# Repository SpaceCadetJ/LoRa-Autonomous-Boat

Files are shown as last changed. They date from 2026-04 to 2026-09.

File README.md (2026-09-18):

# LoRa Autonomous Boat Controller

An embedded-systems project spanning **STM32 firmware, LoRa communication, PCB reconstruction and a documented V2 redesign**. The original university boat controller is preserved as V1; the next vehicle node and a voice/text/location handheld are under development.

**Current milestone: engineering review edition.** The schematics, source code, parts and build procedures are available for inspection. V2 is not fabrication-ready, and the preserved V1 firmware build is not hardware-qualified.

[Portfolio case study](docs/portfolio/README.md) · [Application handbook](docs/applications/README.md) · [Build and assembly guide](docs/build/README.md) · [Latest verification](reviews/codex/design_completion/HANDOFF.md) · [Project history](REPORT.md)

| Existing controller | Developing controller |
| --- | --- |
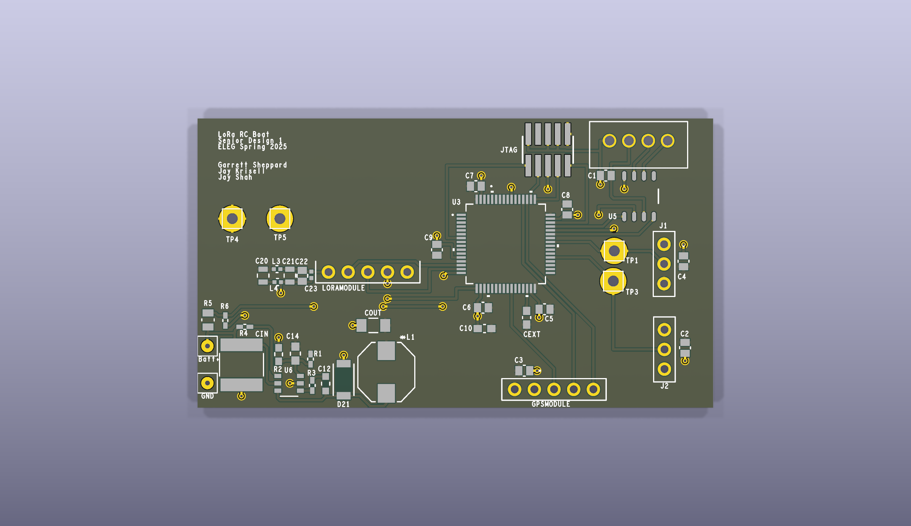
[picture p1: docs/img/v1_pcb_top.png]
V1 controller reconstructed in KiCad
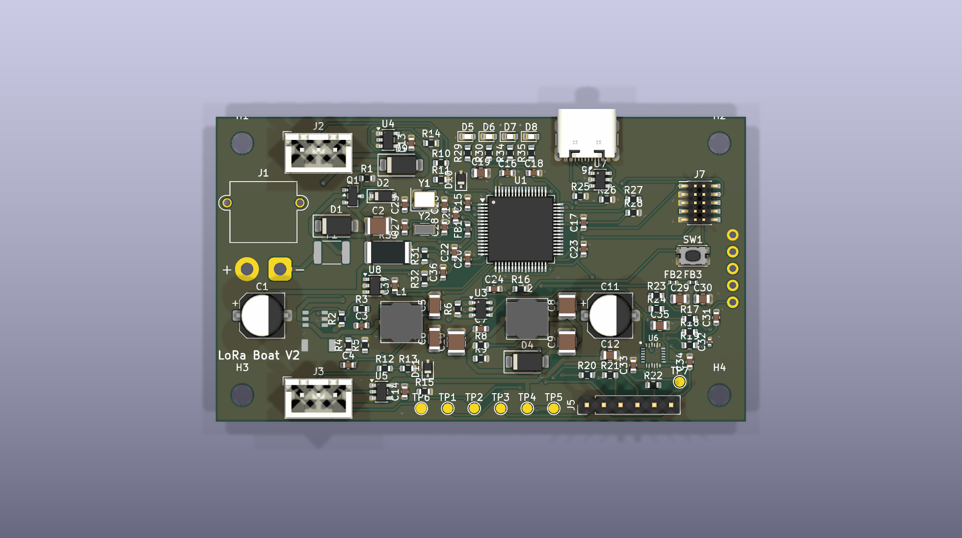
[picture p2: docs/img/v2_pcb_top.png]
V2 vehicle-node CAD draft
|  |  |
| V1: 44 physical components, reconstructed from original fabrication evidence | V2: 118 physical references, 80 × 46 mm board draft |

These are CAD renders. They do not establish that the V2 board has been manufactured or tested.

## Explore the project

Clone or download the repository, then open [pm/index.html](pm/index.html) locally. For the complete interactive workspace with searchable BOMs, datasheets, drawings, connector evidence and assembly/programming guides:

```sh
node pm/tools/serve.mjs
```

Open **http://127.0.0.1:8765/pm/**. The viewer runs locally and requires no account or package installation. GitHub displays the HTML source; it does not run the viewer from a repository file link. See [viewer instructions](pm/README.md).

The [portfolio handoff](docs/portfolio/README.md) and [structured project data](docs/portfolio/portfolio.json) provide captions, asset paths, result evidence and claim boundaries for a portfolio site.

## Architecture and implementation

```mermaid
flowchart LR
  Handset[External handset] <-->|LoRa radio link| Radio[Reyax UART radio]
  Radio <-->|UART| MCU[STM32F446 vehicle controller]
  GPS[GNSS receiver] -->|NMEA UART| MCU
  MCU -->|PWM| ESC[Propulsion ESC]
  MCU -->|PWM| Servo[Steering servo]
  Battery[Battery and regulation] --> MCU
```

V1 firmware is bare-metal C using STM32 HAL/CMSIS, with UART radio commands, GPS parsing and two PWM outputs. The original handset source is not included. The current code has known failsafe, parsing and pin-role issues documented in the [firmware audit](docs/research/FIRMWARE_REVIEW_NOTES.md).

Hardware originated in Cadence OrCAD/Allegro and has been reconstructed in KiCad 9. Python tools generate and inspect schematics, compare complete pin groups and prepare assembly evidence. The viewer uses HTML, CSS and JavaScript with embedded project data; Node.js builds and validates it. GitHub Actions separates portable repository checks from optional native CAD and firmware jobs.

V2 adds draft provisions for protected power, a separate actuator rail, sensing and USB/debug access. The separate [Stage A diagnostic](firmware_v2/README.md) now builds for board identity and inactive actuator outputs. Corrected control firmware, autonomous navigation and the proposed voice/text/location handheld remain development targets. Voice airtime and RC coexistence must be validated before choosing handheld hardware.

## What has been demonstrated

| Deliverable | Recorded result | Evidence |
| --- | --- | --- |
| Readable schematic set | 15 annotated pages, visually inspected | [V1 PDF](docs/img/v1_schematic.pdf), [V2 PDF](docs/img/v2_schematic.pdf), [visual review](reviews/codex/professionalization/VISUAL_REVIEW.md) |
| Electrical preservation | All 172 V1 and 361 V2 pins preserved through the presentation changes | [Independent quality evidence](reviews/codex/professionalization/QUALITY_HANDOFF.md) |
| V1 firmware reconstruction | Two same-host builds produced identical ELF/HEX/BIN hashes; 36,528-byte BIN | [Build record](docs/build/FIRMWARE_HANDOFF.md) |
| Ordering and assembly | BOM reconciliation, held-part decisions, one-board/five-board candidate lists and assembly maps | [Ordering guide](docs/build/ORDERING.md) |
| Navigation and documentation | Searchable parts, selected datasheets, V1 connector atlas, source evidence and version-specific programming guides | [Workspace](pm/README.md), [build guide](docs/build/README.md) |
| Reproducible review | Regression tests, source hashes, native reports and preserved before/after evidence | [Review workflow](docs/build/REVIEW_WORKFLOW.md) |

The integrated V2 ground repair reduces **three unconnected PCB items to zero**, with zero ordinary DRC errors and unchanged warning/parity counts. The [fresh native review](reviews/codex/design_completion/native-review/REVIEW.md) preserves all 533 electrical pins. One V2 ERC warning remains; the strict review also flags the intentional PCB change against its older preservation baseline. Six [component-limit blockers](reviews/codex/design_completion/electrical/README.md) require circuit corrections before fabrication. No range, voice or autonomous-navigation performance is claimed by these software/CAD results.

## Build, review and contribute

- [V1 assembly and inspection](docs/build/ASSEMBLY_V1.md) · [V1 backup/flashing procedure](docs/build/FLASHING_V1.md)
- [V2 assembly review](docs/build/ASSEMBLY_V2.md) · [V2 firmware bring-up plan](docs/build/FLASHING_V2.md)
- [Safe schematic-only regeneration](docs/build/SCHEMATICS.md) · [Reproducible firmware build](docs/build/FIRMWARE_BUILD.md)
- [Independent review workflow](docs/build/REVIEW_WORKFLOW.md) · [Publication and portability record](reviews/codex/publication/README.md)

Do not run full PCB generation or routing merely to refresh drawings. The schematic-only command preserves the existing PCB, project and BOM. Native KiCad checks require KiCad 9; the V1 build requires the recorded GNU Arm toolchain. No CI job flashes real hardware.

The [IMU interface candidate](reviews/codex/imu_interface/README.md) now implements the proposed 1.8 V supply and I2C/interrupt translation in a separately checked schematic. It is available in the V2 viewer; live PCB integration is the next layout task.

## Next milestones

1. Correct the IMU's 1.8 V interface and the five remaining power/signal-limit findings; reconcile schematic-to-PCB differences.
2. Build on the separate Stage A diagnostic: freeze the operational protocol, implement supervised outputs and measure failsafe behavior.
3. Complete part/footprint qualification, the V2 connector atlas and staged physical bring-up.
4. Validate voice quality, radio airtime and RC scheduling before developing the handheld.

## Provenance and attribution

The original controller was a University of Arkansas EECS senior-design team project; the repository identifies May 2025 fabrication evidence. The current reconstruction, documentation and review tooling include AI-agent-assisted development. Individual original team contributions should be confirmed before using first-person portfolio claims.

`Allegro/` preserves original source evidence. Read [provenance and conversion limits](docs/A0_PROVENANCE.md) before interpreting the reconstructed geometry or inferred drill data. Third-party firmware and tools retain their existing notices; no new project-wide license is granted by this documentation.

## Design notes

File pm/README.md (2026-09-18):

# LoRa engineering workspace

## Current IMU placement review

The [placement review](../reviews/codex/imu_placement/README.md) maps the twelve additions and a filter reserve. Courtyards fit, but 136 native errors identify required copper work; complete 6S fit is unresolved. The V2 Design viewer includes the obstacle map. Start with the new circuit/power/routing restart order.

## Current IMU correction candidate

The [isolated 1.8 V IMU circuit](../reviews/codex/imu_interface/README.md) is available in the V2 Design viewer. Exactly five existing connections change; native comparison and ERC checks pass their scoped acceptance. It is not integrated into the PCB, BOM or firmware contract. Start with its placement/routing handoff; the six live electrical blockers remain open.

## Current application and diagnostic edition

Use **Use by application** for the [application handbook](../docs/applications/README.md), with separate V1 bench, V2 boat, rover, telemetry and handheld guides. The separate [V2 Stage A diagnostic](../firmware_v2/README.md) builds for board identity and inactive actuator outputs; it is not operational control firmware. The [component-limit review](../reviews/codex/design_completion/electrical/README.md) identifies six circuit blockers beyond the CAD warning count. Current affected parts are held in the ordering package. The integrated ground repair now has zero unconnected items and zero ordinary DRC errors, with unchanged warning/parity counts. V2 ordering has 74 candidate, 33 held and 11 bare-feature references. Start at the [current handoff](../reviews/codex/design_completion/HANDOFF.md); the next circuit packet is the IMU 1.8 V supply/interface correction. Earlier ground-count, no-V2-image and no-publication statements below describe previous checkpoints.

Open [index.html](index.html) directly in a browser. The generated page contains its data and application code; no install or build step is required to view it. Keep it in this repository so images, schematics and evidence links resolve.

For the local HTTP viewer, run from the repository root:

```powershell
node pm/tools/serve.mjs
```

Then open <http://127.0.0.1:8765/pm/>. The server binds only to this computer, serves selected project paths and does not modify repository files. Stop it with Ctrl+C. This does not publish the project.

## What to explore

- Overview: phases, evidence gates and the next review tasks.
- Design: V1/V2 schematic sheets, available PCB renders, PDF drawings and source KiCad files. Choose a view and zoom to inspect it.
- BOM: searchable V1/V2 parts, component details and selected manufacturer datasheets. An unmapped part explicitly says its exact datasheet is not yet linked. Prices are dated source estimates.
- Build & program: V1/V2 ordering candidates, held and external parts, assembly maps, inspection steps, firmware build and separate programming procedures. The guides distinguish the unqualified V1 image from the V2 Stage A diagnostic and future operational firmware.
- Connector atlas: V1 connector pins, firmware cross-references, voltage expectations and known defects. Bench readings are expectations, not measurements.
- Software: current source and proposed correction files, clearly separated from integrated firmware.
- Verification: independent V1 checks, primary reports and input fingerprints.
- Traceability: V1 findings linked to the primary's V2 requirements and acceptance methods.
- Decisions: working defaults, open choices and private browser notes. Notes stay in this browser; export the handoff to save a copy. They are not written back to project files.
- Documents: searchable embedded documentation and the repository file map.

## Refresh evidence

For the published edition, recorded firmware/primary reports are stored under `docs/build/evidence/`; V1 schematic generation has verified tracked inputs. Rebuilding the viewer no longer needs this workstation's ignored CAD/compiler caches. The current portable native snapshot is [design_completion/native-review](../reviews/codex/design_completion/native-review/REVIEW.md). Downloaded source archives can rebuild without Git, using a `source-archive` revision label. See the [publication record](../reviews/codex/publication/README.md).

Only after checking [ownership](../FILE_OWNERSHIP.md), current [handoff](../HANDOFF.md), Git status and primary release notes:

```powershell
node pm/tools/build.mjs
node pm/tools/validate.mjs
```

The builder reads evidence and writes only `pm/index.html` and `pm/status.json`. It never invokes CAD/firmware generators. In HTTP mode use Refresh after building; with a directly opened file, reload the page. Editing `index.html` directly loses changes on rebuild; edit `index.template.html` instead.

The snapshot records branch/HEAD and SHA-256 hashes of consumed text/report inputs. Working files may differ from HEAD. Changed-during-build detection covers hashed inputs, not a repository lock or a full media/CAD archive. Images and CAD links load current files from the repository; independent S2 results refer to the separately identified historic snapshot.

## Earlier schematic review edition — 2026-09-17

Jay authorized Codex to improve schematics, ordering/assembly and programming documentation while the other agent is inactive. This supersedes earlier conservative primary-only edit reservations for the delivered packet. Start at [build and programming](../docs/build/README.md) and the [professionalization handoff](../reviews/codex/professionalization/HANDOFF.md), then check the latest ownership before editing.

All fifteen schematic pages now have grouped components, separate label/property spacing and engineering annotations. PDF/SVG exports share a source/output hash manifest. The latest independent numbered review is captured automatically in the viewer: all 172 V1 and 361 V2 electrical pins preserve the prior design. V1 ERC is clean; V2 has one pre-existing pin-type warning, so the strict combined review remains failed. V2 PCB checks report three unconnected entries, 101 warnings and 212 parity entries. Fabrication is not approved.

The purchasing packet distinguishes complete BOM reviews from partial candidate import lists: V1 has 20 candidate / 18 held / 6 bare-feature references; V2 has 90 / 17 / 11. Assembly maps, optional population decisions and first-power procedures are linked. Existing firmware builds reproducibly on the recorded toolchain but preserves original defects; no hardware was flashed and there is no V2 firmware image. The manual CI definition is local and has not been activated or pushed.

**Next smallest task:** classify V2's three open PCB connections against their exact pad/net evidence, and review the pre-existing U6 AD0 warning against the selected sensor interface. Produce a correction proposal before changing circuit intent or routing. Then freeze the V2 pin/protocol contract for a separate diagnostic firmware project. Voice/text/location and RC coexistence remain required before handheld hardware selection.

## Historical evidence and remaining limits

V1 independent review is at `639e08f`: all 172 pin memberships agree, ERC has zero violations, and DRC has zero errors/zero unconnected with 67 warnings. Native schematic/PCB comparison adds 139 value/name warnings; these concern metadata and update workflow, not electrical pin connectivity. V5 drill diameters and independent whole-film XOR remain unresolved. See [S2 verification](../reviews/codex/S2_VERIFICATION.md).

V2 remains a draft. The latest CSV has 67 component rows totaling 118 parts; older reports said 68 lines and two open connections. Current independent checks supersede those counts. The V1 review has 35 distinct findings linked to 45 V2 requirements. Standalone protocol correction files remain proposals; they were not integrated by the preserved-V1 compilation. V2 connector coverage and complete datasheet mapping are subsequent packets.

The independent V2 snapshot/ERC/DRC inventory is now complete and separately identified from historic S2. The current `REQ-CTL-01` text governs proposed deadlines; reconcile its 1.0 s default with the older 500 ms prompt summary before timing acceptance.

Resume through this file and [Codex checkpoint](../reviews/codex/README.md). Work one bounded packet in owned paths, record exact evidence and limitations, then append the next task to the handoff.

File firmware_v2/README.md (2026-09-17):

# V2 Stage A: board identity diagnostic

This is the first separate V2 executable, built for STM32F446RET6. It is a **development diagnostic**, not RC, navigation or handheld firmware. The current board has unresolved electrical issues; resolve the [electrical review](../reviews/codex/design_completion/electrical/README.md) before powering an assembly. Keep actuator loads disconnected throughout Stage A.

## Build on your computer

From the repository root, using Python 3.10+ and GNU Arm GCC (the existing STM32CubeIDE installation is auto-detected on Windows):

```text
python firmware_v2/tools/build.py check
python firmware_v2/tools/build.py build
```

If the compiler is elsewhere, add `--toolchain` with its `bin` directory. Outputs are confined to a new, empty directory under `firmware_v2/build/`; use `--out firmware_v2/build/stage_a_repeat` for a second build. Existing output directories are not overwritten. No compiler download, probe discovery or programmer command is performed.

The default build creates `firmware_v2/build/stage_a/v2_stage_a_unqualified.elf`, `.hex`, `.bin`, `.map` and `manifest.json`. The manifest records compiler, exact inputs, command output, load address, image size and hashes. A failed build has `status: build_failed`; never use artifacts from it. Compare the manifest with the exact image before any later programming.

This target reuses ST's preserved CMSIS headers, system/startup files and F446RE linker script from `firmware/`. It does not compile V1's application, change V1 sources or require CubeMX. There is no V2 `.ioc` yet. The [pin contract](board_contract.json) verifies seven MCU pin functions, net names and peer pads against the recorded native schematic export and checks that current V2 schematic inputs still match that export. That check covers electrical membership, not footprint/cable orientation.

## Expected behavior after approved bench programming

First complete the power and SWD prerequisites in the [V2 programming guide](../docs/build/FLASHING_V2.md), including backups, image identity and readback verification. This diagnostic is not permission to power the present circuit. Start from a hardware reset, not a debugger jump into `main` after running another image.

| Item | Expected observation; not yet measured on hardware |
| --- | --- |
| ESC PC6 / U1-37 and SERVO PA8 / U1-41 | Output latch set low before GPIO output mode. No timer/PWM initialization or pulse generation. Check both MCU and header signals with loads disconnected. |
| D6 / PC1 | Toggles every nominal 500 ms, one complete on/off cycle per second; this is a diagnostic heartbeat, not radio-link status. |
| D7 / PC2 | Off; no GNSS driver or fix is claimed. |
| D8 / PC3 | On to identify the diagnostic edition; it does not mean the vehicle is ready to arm. |
| SWD PA13 / PA14 | Reset configuration retained; inspect `v2_diagnostic` with the matching ELF symbols. |
| Radio, IMU, USB, ADC, GNSS and other GPIO | No drivers initialized; those pins retain reset state. A connected module may still have its own power-on behavior. |

In CubeIDE's debugger Expressions view, add `v2_diagnostic`. The structure is volatile RAM and contains:

| Field | Interpretation |
| --- | --- |
| `magic` | `0x3252564C`, identifying this V2 diagnostic record |
| `version` | `1`, the record format |
| `stage` | `2` after initialization; `0xE1` unexpected clock, `0xE2` SysTick setup failure; `0xF1`–`0xF5` processor fault/NMI |
| `reset_flags`, `device_id` | Raw RCC reset flags and DBGMCU IDCODE for the bench record |
| `core_clock_hz` | Nominal 16,000,000 from the internal HSI; no external-crystal or USB-clock qualification |
| `milliseconds`, `heartbeat_edges` | SysTick count and LED edge count; sampling while halted will stop progress |

Fault handlers attempt to hold the MCU actuator pins low and stop for diagnosis. A corrupted stack or bus fault can prevent a C handler from completing. They do **not** implement the later watchdog/recovery requirements. This stage is not evidence of a safe control supervisor, controlled startup at the external buffer, brownout performance or an operational link-loss failsafe.

## Troubleshooting and next stage

If the builder rejects the pin contract, compare the changed schematic with its native export and review the mapping before updating evidence. Do not disable the guard. If SWD cannot attach, use the power/reset/cable checks in the programming guide; the diagnostic does not provide USB DFU, a serial console or radio commands. If the heartbeat does not appear, inspect the RAM record and PC1 waveform before assuming the LED polarity, population or MCU clock is correct. Stop if a rail or actuator waveform is unexpected.

Record board/rework identity, firmware hash, power rails/current, SWD ID, reset flags, LED/PC1 period, and both actuator signals across reset. Stage B adds the control supervisor, timers and watchdog only after the electrical design and output behavior are accepted. Application-specific use and release gates are in the [application handbook](../docs/applications/README.md).

The register behavior is based on [ST RM0390](https://www.st.com/st-web-ui/static/active/en/resource/technical/document/reference_manual/DM00135183.pdf), the local ST CMSIS definitions and [Arm's SysTick API](https://arm-software.github.io/CMSIS_6/main/Core/group__SysTick__gr.html). Compilation is software evidence; none of the expected physical observations above has been performed.

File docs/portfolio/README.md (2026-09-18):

# LoRa controller: from legacy board to reviewable platform

**Embedded systems, PCB reconstruction and engineering documentation.** This project turns an existing university boat-controller design into an inspectable KiCad workspace, with an evolving multifunction vehicle node and a future handheld. The current milestone is a documented engineering review edition with application guides and a separate V2 identity diagnostic. It is not a production release.

> A LoRa vehicle-controller project combining STM32 firmware, PCB reconstruction and an interactive engineering workspace. The repository preserves the original boat hardware, presents fifteen annotated schematic pages, traces connectors and parts to source evidence, and provides a reproducible V1 firmware build. A second-generation controller and voice/text/location handheld are under development, with verification results and unresolved design decisions recorded alongside the design.

[Explore the workspace](../../pm/index.html) · [Build and assembly guide](../build/README.md) · [Structured portfolio data](portfolio.json) · [Latest engineering handoff](../../reviews/codex/design_completion/HANDOFF.md)

## Context and contribution boundaries

The original University of Arkansas EECS senior-design team developed the boat controller in Cadence OrCAD/Allegro; the repository identifies May 2025 fabrication evidence. The present work reconstructs that legacy design in KiCad 9, investigates its defects, improves navigation and documentation, and prepares a V2 redesign. Original provenance and conversion limits are recorded in [A0_PROVENANCE.md](../A0_PROVENANCE.md).

The reconstruction, tooling and documentation include AI-agent-assisted development and independent review packets. This page describes repository deliverables, without assigning the original team's individual hardware or firmware contributions to Jay. Confirm his original role before writing a first-person portfolio account.

## Design and software

The V1 source implements a UART-connected Reyax LoRa radio interface, NMEA GPS parsing and 50 Hz PWM outputs for an ESC and steering servo around an STM32F446. Its bare-metal C firmware uses STM32 HAL/CMSIS and STM32CubeIDE/CubeMX project inputs. These are implementation facts, not newly measured radio or navigation performance. The handset source is absent from this repository. See the [firmware review](../research/FIRMWARE_REVIEW_NOTES.md).

```mermaid
flowchart LR
  H[Handset: external to this repository] <-->|LoRa link| R[Reyax UART radio]
  R <-->|UART| M[STM32F446 vehicle controller]
  G[GNSS receiver] -->|NMEA UART| M
  M -->|PWM| E[ESC / propulsion]
  M -->|PWM| S[Steering servo]
  B[Battery / power conversion] --> M
```

The V2 CAD draft expands power protection, actuator-rail separation, sensing and debug provisions. Fail-safe control, watchdog behavior, corrected parsing, heading hold and waypoint navigation remain implementation/acceptance work. The proposed handheld must support **voice, text and location** alongside RC control; radio airtime and worst-case control blocking must be validated before selecting its hardware. [Requirements](../V2_REQUIREMENTS.md) and the [platform concept](../../reviews/codex/PLATFORM_CONCEPT.md) distinguish these targets from delivered capabilities.

Python tools generate and review CAD, assemble purchasing evidence and compile preserved firmware. The local viewer uses HTML, CSS and JavaScript with embedded data; Node.js builds and validates the workspace. GitHub Actions defines automatic repository/evidence checks and separately opted-in native CAD/firmware jobs. A repository check is not hardware acceptance; consult the actual published run before claiming hosted execution. See [review workflow](../build/REVIEW_WORKFLOW.md).

## Demonstrated results

| Result | Evidence and scope |
| --- | --- |
| Fifteen grouped, annotated schematic pages | [Visual review](../../reviews/codex/professionalization/VISUAL_REVIEW.md); all pages inspected after PDF/SVG export |
| Presentation edits preserve all 533 electrical pins | [Final independent review](../../reviews/codex/professionalization/QUALITY_HANDOFF.md): V1 44 components / 172 pins, V2 114 electrical components / 361 pins; no value, footprint or net-name changes |
| Reproducible V1 compile and link | [Firmware evidence](../build/FIRMWARE_HANDOFF.md): two same-host builds produced identical ELF/HEX/BIN hashes; BIN 36,528 bytes, RAM reservation 4,496 bytes; preserved behavior remains unqualified |
| Traceable ordering and assembly material | [Procurement evidence](../build/PROCUREMENT_HANDOFF.md): 44 V1 / 118 V2 physical references reconciled; held/optional/external parts separated from partial candidate import lists |
| Navigable engineering workspace | [Viewer QA](../../pm/QA.md): searchable BOM, selected datasheets, connector evidence, drawings, build guides and review results; desktop/mobile checks and 203 local HTTP links passed at the recorded checkpoint |
| Regression checks for the editing workflow | [Publication review](../../reviews/codex/publication/QUALITY_PORTABILITY.md): 18 acceptance tests passed; isolated schematic generation preserves PCB/project/BOM |

The [current native check](../../reviews/codex/design_completion/native-review/REVIEW.md) records V1 ERC 0 errors/0 warnings and V2 ERC 0 errors/1 existing warning. The integrated ground repair reduces V2 unconnected items from three to zero with zero ordinary DRC errors; all 118 footprints and pad assignments remain unchanged. PCB warnings and schematic-parity findings remain. The strict combined review also flags the intentional PCB correction against the older preservation baseline. Six component-limit blockers still prevent fabrication approval. No physical assembly, flashing, bench qualification or range testing was performed during this edition.

## Portfolio visuals

Use the labels below when copying assets into a portfolio. PCB renders show CAD geometry, not photographs of a tested assembly. The V2 render is a draft, not a released product.

| Asset | Suggested caption |
| --- | --- |
| [V1 PCB render](../img/v1_pcb_top.png) | Legacy boat-controller PCB reconstructed in KiCad from preserved source evidence |
| [V2 PCB render](../img/v2_pcb_top.png) | Multifunction vehicle-controller CAD draft; electrical and layout review ongoing |
| [V1 schematic overview](../img/v1_sch_Root.svg), [V2 overview](../img/v2_sch_root.svg) | Functional sheet organization for the existing controller and redesign |
| [V1 schematic PDF](../img/v1_schematic.pdf), [V2 schematic PDF](../img/v2_schematic.pdf) | Annotated circuit drawings with subsystem notes and explicit review status |
| [V1 assembly map](../../hardware/manufacturing/v1/assembly_top.svg), [V2 assembly map](../../hardware/manufacturing/v2/assembly_top.svg) | Reference-designator maps for locating candidate parts during assembly review |

A separate [V2 Stage A diagnostic](../../firmware_v2/README.md) now builds reproducibly for board identity, heartbeat and inactive actuator outputs. The [application handbook](../applications/README.md) covers five use cases with explicit release gates. The [component-limit review](../../reviews/codex/design_completion/electrical/README.md) identifies six electrical blockers that remain after copper cleanup.

The [IMU correction candidate](../../reviews/codex/imu_interface/README.md) now provides a concrete 1.8 V supply and translated I2C/interrupt schematic, with exact pin-delta checks and a reviewed TI-specific footprint. It is separate from the live PCB and purchasing package; placement, routing and physical qualification remain pending.

## Next engineering milestones

1. Correct the IMU's 1.8 V supply/interface and the remaining power/signal-limit findings, then reconcile schematic-to-PCB discrepancies before layout release.
2. Extend the implemented Stage A diagnostic after electrical acceptance: freeze the operational protocol, implement output supervision and measure failsafe behavior.
3. Finish the V2 connector atlas, exact-part qualification and complete population/purchasing decisions; perform recorded staged board bring-up.
4. Measure voice quality, airtime and RC coexistence, then develop the handheld and application interfaces.

For portfolio updates, preserve the distinctions in [portfolio.json](portfolio.json): **source-implemented**, **independently checked**, **proposed** and **not tested**. Pin the portfolio's repository link to the actual integration commit after publication; this handoff deliberately does not invent a commit, public site URL or individual team role.

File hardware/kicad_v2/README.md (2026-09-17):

# LoRa Boat Controller V2 — KiCad 9 project (Phase C draft)

Electrical intent is generated from `tools/v2_design.py`; schematic presentation is controlled by `../kicad/tools/schematic_layout.py` and the shared renderer. Keep source and generated outputs together. The [build guide](../../docs/build/README.md), [schematic editing procedure](../../docs/build/SCHEMATICS.md) and [current independent checks](../../reviews/codex/professionalization/QUALITY_HANDOFF.md) describe the latest review packet. Existing PCB routing is preserved by schematic-only commands.

| File | What it is |
|---|---|
| `LoRa_Boat_Controller_V2.kicad_pro` | project: netclasses (Default 0.25 mm / 0.15 mm, Power 0.6 mm / 0.2 mm), DRC severities, board rules (0.127 mm min clearance / track, 0.3 mm edge, 0.6 mm min via) |
| `LoRa_Boat_Controller_V2.kicad_sch` + `Power/MCU/Radio/Navigation/Actuators/Debug.kicad_sch` | root sheet with hierarchical pins + six sub-sheets (ERC: 0 errors, 1 accepted warning — U6 SDO/AD0 tied to GND) |
| `LoRa_Boat_Controller_V2.kicad_pcb` | 80 × 46 mm 2-layer board, 118 footprints, GND pours both sides, autorouted with freerouting (see `tools/route_v2.py`) |
| `LoRa_Boat_Controller_V2.kicad_sym` / `.pretty/` | project symbols (VSERVO) and footprints (QFN-24 3 × 3 mm 0.4 mm no-EP for the ICM-20948) |
| `fp-lib-table`, `sym-lib-table` | project libraries: `LoRa_Boat_Controller` (reused V1 footprints/symbols from `../kicad/`) and `LoRa_Boat_Controller_V2` |
| `_build/` | (git-ignored) DSN/SES, freerouting log, DRC/ERC reports, placement report, BOM JSON |

## Tool chain (run from the repo root)

```bash
python hardware/kicad_v2/tools/gen_v2.py check                                   # design-rule sanity: every pin either in a net or in NC_PINS
python hardware/kicad_v2/tools/gen_v2.py sch                                     # schematic-only refresh; preserves PCB/project/BOM
python hardware/kicad/tools/export_review.py                                    # PDF/SVG rendering only; no CAD generation
"C:/Users/Jay/AppData/Local/Programs/KiCad/9.0/bin/python.exe" hardware/kicad_v2/tools/placement_check.py   # courtyard overlaps / parts off the board
"C:/Users/Jay/AppData/Local/Programs/KiCad/9.0/bin/kicad-cli.exe" sch erc --severity-all -o hardware/kicad_v2/_build/erc.rpt hardware/kicad_v2/LoRa_Boat_Controller_V2.kicad_sch
"C:/Users/Jay/AppData/Local/Programs/KiCad/9.0/bin/python.exe" hardware/kicad_v2/tools/route_v2.py all     # DSN (B.Cu GND plane only) -> freerouting -> SES import -> pour fill
"C:/Users/Jay/AppData/Local/Programs/KiCad/9.0/bin/kicad-cli.exe" pcb drc --severity-error -o hardware/kicad_v2/_build/drc.rpt hardware/kicad_v2/LoRa_Boat_Controller_V2.kicad_pcb
```

`gen_v2.py pcb` explicitly replaces the PCB with an unrouted board; `gen_v2.py all` (also the legacy no-argument default) regenerates libraries, schematic, project, unrouted PCB and BOM. Use those only for an intentional full rebuild. `check`, `bom` and `sch` have separate scopes; `sch` no longer destroys routing. An isolated regression test verifies that separation.

`route_v2.py` needs Java 21 and `freerouting-2.1.0.jar` at `%LOCALAPPDATA%\freerouting\` (or `FREEROUTING_JAR`). Routing is separate from schematic presentation; do not reroute merely to refresh drawings. The routing command above remains an explicit board mutation, outside the presentation-only workflow.

## Design source (`tools/v2_design.py`)

- `PARTS`: ref -> (symbol, footprint, value, MPN, manufacturer, sheet, description). `NETS`: net -> pins as `REF-number` or `REF.pinname`. `NC_PINS`: pins deliberately left open (everything else must be in a net, `gen_v2.py check` fails otherwise).
- `POWER_NETS`: which nets are drawn with power symbols; `SHEETS`: sheet names/paper/descriptions; `PLACE`: ref -> (x, y, rotation) in board mm from the top-left corner; `MOUNT_HOLES`, `BOARD_W/H`, `KEEPOUTS`.
- `PRICE_USD` / `PRICE_DATE`: qty-1 catalogue prices used by `docs/BOM_V2.csv` (estimates; re-quote at order time).

Requirement traceability is in the schematic sheet descriptions and in `docs/V2_REQUIREMENTS.md` (REQ-xx ids); the design decisions still open for Jay are in `BLOCKERS.md`.

## Known state of this draft

Current independent results supersede the historical routing count below: **3 unconnected entries, 101 DRC warnings, 212 schematic-parity entries**, zero DRC errors; ERC has one pre-existing U6 AD0 pin-type warning. No fabrication acceptance. [Assembly maps and procedures](../../docs/build/ASSEMBLY_V2.md) are now available; physical orientation and device/footprint qualification remain open.

- DRC 0 violations, **2 unconnected GND connections**: two pour islands (near U1 at board (42, 18.5) mm and near U7 at (55.7, 9.2) mm) are fenced in by other-net tracks on both layers. `route_v2.py import` stitches what it can (one of three islands on this layout); the last two need a hand-placed via each in KiCad (or a rip-up of the fencing track). The next layout pre-places a GND via next to every fine-pitch GND pad before routing to avoid this.
- Autorouted, not hand-optimised: expect to tidy the buck-converter loops (U2/L1/D3/C5-C6 and U3/L2/D4/C8-C9), the crystal traces and the USB pair before fabrication; keep the placement.
- Silkscreen is reference designators only; no assembly drawing yet.
- Footprints for new parts come from the KiCad 9 standard library on this machine (`KICAD_FOOTPRINT_DIR`), embedded into the board at generation time.

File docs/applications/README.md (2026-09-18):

# Application handbook

Use this project as a documented route from the existing boat controller to a reusable vehicle and communications platform. Choose an application below, identify its hardware and software revision, then follow its preparation, operating sequence and acceptance checks.

**The current release is an engineering review edition.** V1 has a reproducible preserved-source firmware build and an instrument-only bench procedure. V2 is a developing vehicle board. Powered vehicle operation and the handheld have not been qualified. A drawing, compiled image or passing software test alone does not release a physical application.

## Choose an application

| Application | Available now | Required before normal operation | Guide |
|---|---|---|---|
| Existing V1 boat controller | Inspect the circuit, preserve firmware, reproduce the build and characterize unloaded signals | Board-specific electrical corrections; corrected control supervisor; measured output and fault tests | [V1 bench and legacy RC](V1_BENCH.md) |
| Updated V2 boat controller | Review power/wiring and build the Stage A identity diagnostic | Accepted board revision, operational V2 firmware and successful first-article tests | [V2 boat](V2_BOAT.md) |
| Rover with one ESC and steering servo | Plan reuse of the two vehicle outputs and document the selected motor-controller behavior | Rover profile, verified neutral/braking behavior and measured tests | [Rover adaptation](ROVER.md) |
| Remote position / telemetry node | Inspect V1 position-message behavior and prepare an unloaded receiver demonstration | Fix freshness, message identity, bounded reporting and receiver implementation | [Position and telemetry](TELEMETRY.md) |
| Handheld communicator | Develop the voice, text and location specification and coexistence test | Two endpoints, firmware, audio hardware, delivery behavior and measured radio budget | [Voice, text and location](HANDHELD.md) |

Each guide distinguishes **source behavior**, **work that can be performed now**, and **operation after release**. “After release” is a procedure to implement and test, not a hidden existing command or feature. Follow the linked current engineering evidence when a design changes; record any disagreement before connecting hardware.

## Start with a complete build identity

Create an [acceptance record](ACCEPTANCE_RECORD.md) for each unit. Record the board revision and serial, population option, harness labels, firmware commit and SHA-256, radio/module identity, protocol version, calibration and test results. Keep photographs and measured traces with that record. A V1 image and V2 circuit must never be paired just because both use an STM32F446.

Use the [ordering guide](../build/ORDERING.md) for candidate BOM imports and held parts, then the [V1](../build/ASSEMBLY_V1.md) or [V2](../build/ASSEMBLY_V2.md) assembly procedure. The purchasing exports are partial review lists. Antennas, fitted radio/GNSS modules, connectors and cable mates, enclosure, power source, programmer and application loads also need exact identities. Do not infer a complete kit from the controller BOM.

The [V2 electrical review](../../reviews/codex/design_completion/electrical/README.md) identifies unresolved IMU voltage-domain and power/interface component-limit conflicts. Resolve these against the actual assembly before powering it, including for the new [Stage A diagnostic](../../firmware_v2/README.md). Its low MCU output state does not repair the circuit or qualify an external actuator signal.

## V1 and V2 are different wiring contracts

| Function | Preserved V1 | Current V2 source intent |
|---|---|---|
| Motor-command output | PC6/TIM3_CH1 → **STEERINGSERVO1 pin 2** | PC6/TIM3_CH1 → level shifter → **J2 pin 1 (ESC)** |
| Steering output | PA8/TIM1_CH1 → **SPEEDCONTROLLER1 pin 2** | PA8/TIM1_CH1 → level shifter → **J3 pin 1 (SERVO)** |
| Actuator power | Both header pin-1 connections are **+3V3**; no assumed BEC compatibility | Separate actuator rail and power-source choices; qualify the actual population |
| Radio | UART4 PA0 TX / PA1 RX, 115200 8N1; PA3 reset is unconfigured | Same UART pins with acknowledged setup and reset recovery to implement |
| GNSS | USART3 PC10 TX / PC11 RX, 9600 8N1; debug shares TX; PB0 drives header pin 3 LOW | Dedicated GNSS UART and PB0 as PPS input; baud belongs to the frozen module/profile |
| Programming | JTAG1, verified electrical SWD pin mapping | J7, reviewed V2-specific image required |

This is an electrical comparison, **not a cable-face or left-to-right view**. Check physical pin 1, viewing side and mating connector independently. The [V1 atlas](../atlas/README.md) and [V2 programming contract](../build/FLASHING_V2.md) give the source detail. Hardware source, schematic, PCB, harness and firmware must agree at the same revision.

## What “finished” means for an application

An application is ready when its exact assembly can be ordered, assembled, programmed, operated and recovered by another person using the release package, and the named acceptance cases have measured passing results. Release requires:

1. Accepted electrical and PCB review, complete selected BOM, final manufacturing files and assembly orientation record.
2. Reproducible board-specific firmware and matching peer software, with backup/restore instructions and a versioned interface contract.
3. Measured startup, shutdown, reset, loss-of-link, malformed-message, power and application tests on the actual unit.
4. Operating limits, controls, fault indications and recovery steps demonstrated to match this handbook.

The [review workflow](../build/REVIEW_WORKFLOW.md) handles source and evidence checks; the [acceptance record](ACCEPTANCE_RECORD.md) handles physical results. Failed or unperformed cases remain open. The [application index](applications.json) exposes the same status and next task to the viewer and portfolio tooling.

## Current design gate: IMU placement

The [placement review](../../reviews/codex/imu_placement/README.md) finds physical courtyard space but 136 native copper/mask/clearance errors on the isolated study. This does not advance any application to powered acceptance. Live board, purchasing and Stage A contracts are unchanged; resolve the bias-filter amendment and 6S power envelope before final routing and application bring-up.

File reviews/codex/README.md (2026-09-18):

# Start here: Codex review checkpoint

## Latest bounded packet: placement feasibility

[Placement study and next task](imu_placement/README.md) preserves all original copper and placements. It verifies courtyard fit but rejects integration on untouched copper, with 136 native errors. Next: disposition the recommended bias filter and establish the 6S power-package envelope before final routing.

## Latest bounded packet: IMU interface candidate

[IMU candidate and next task](imu_interface/README.md) implements and independently checks the 1.8 V supply/bus/interrupt circuit in an isolated schematic. Live CAD and purchasing exports remain unchanged. Assess placement on a corrected PCB copy before integration.

## Current application and electrical completion packet

Start with [design_completion/HANDOFF.md](design_completion/HANDOFF.md), [application guides](../../docs/applications/README.md) and the [V2 diagnostic](../../firmware_v2/README.md). The current work connects application procedures to actual board/firmware readiness, repairs the three ground connections, identifies six component-limit blockers, and adds a pin-checked Stage A image. The previously published integration is on `main` and `v2-design`; earlier primary-ownership and no-push statements below are historical. Operational control firmware, electrical corrections and bench qualification remain separate open work.

## Earlier checkpoint — 2026-09-17, schematic and build review edition

Read [professionalization/HANDOFF.md](professionalization/HANDOFF.md) and [docs/build/README.md](../../docs/build/README.md) first. Jay authorized Codex to continue the professional schematics, purchasing/assembly, V1/V2 programming and review workflow while the other agent is inactive. Current ownership supersedes the earlier reservations below.

The delivered packet includes fifteen annotated schematic pages, verified preservation of 172 V1 / 361 V2 pins, a protected schematic-only generator command, ordering candidates/holds and assembly maps, a reproducible unqualified V1 firmware build, separate flashing guides and a manual CI definition. Strict combined review remains failed for one pre-existing V2 ERC warning. V2 also has three unconnected PCB entries, warnings/parity discrepancies and no firmware image; it is not fabrication-ready. The viewer now presents these current results beside the historic S2 evidence.

The next smallest packet is a pad-level disposition of the three V2 open connections and U6 AD0 warning, followed by a reviewed V2 pin/protocol contract. Avoid full CAD regeneration/rerouting during documentation work. All source/output hashes, reproduction commands and remaining limits are in the linked handoff. The hourly continuation prompt has been updated to this scope and remains quiet for non-actionable results.

## Previous checkpoint — 2026-09-17, viewer delivery

This section supersedes the initial intake state below. Resume through [pm/README.md](../../pm/README.md), then the latest root [handoff](../../HANDOFF.md) and [ownership](../../FILE_OWNERSHIP.md). Check Git status/HEAD before writing; the primary remains responsible for CAD, firmware, generators and Git integration. Codex owns `pm/**`, `docs/atlas/**`, `reviews/**`; coordination files are append-only.

- The local [interactive viewer](../../pm/index.html) includes V1 and V2 design assets, searchable BOMs and selected manufacturer references, the V1 connector atlas, source/protocol proposals, independent versus reported checks, findings-to-requirements links, decisions, documents and exported review notes. It opens directly or through the loopback server described in its README.
- [V1 atlas](../../docs/atlas/README.md): 12 connectors/test points and 36 pins, traced from source evidence with firmware citations. Physical orientation and bench readings remain unverified. V2 atlas is not yet done.
- [S2 independent verification](S2_VERIFICATION.md): historic `639e08f` only. All 172 pins / 44 parts agree, ERC 0, DRC 0 errors / 0 unconnected / 67 warnings, hole centers 53/53. Additional native parity: 139 classified metadata warnings. No electrical mismatch found; no-change schematic update workflow and V5 drill sizes remain unverified. The earlier global blocked label was narrowed; raw results did not change.
- Primary V2 release at `a6316e9` / `v2-design-draft` reports 118 parts, 71 nets, 68 grouped BOM lines and two open ground connections. The current CSV independently parses as 67 component rows totaling 118 parts; the report count is stale. Treat V2 numbers as reported, pending independent verification. Current source documents contain 35 distinct V1 findings and 45 requirements.
- Standalone files in `firmware_prototype/` are uncompiled review proposals. No functional firmware fix was integrated.
- Jay requires **voice + text + location**. The primary handoff additionally reports expanded vehicle/fleet scope; wait for its architecture/requirements documents before asserting that expanded scope is implemented. Validate voice/RC coexistence before radio selection. `REQ-CTL-01` currently says a default **1.0 s** loss timeout; the primary prompt's **500 ms** summary conflicts and must be reconciled in the RF packet.

**Next smallest packet:** independently snapshot the released V2 inputs, record hashes and run ERC/DRC plus part/net/BOM inventory in `reviews/codex/` without invoking generators or changing source CAD. Then review one power/control subsystem against actual requirements. Later packets: V2 atlas, protocol prototype build/tests, quantitative voice/RC coexistence, handheld/application views from released documents.

An hourly continuation automation is active. It works bounded packets in released scopes and should notify only on meaningful deliverables, new blocking findings or required decisions. Account/runtime availability may interrupt runs; these files are the durable resume context.

## Historical initial intake — retained for context

Updated 2026-09-17 UTC. User objective: understand and improve the conversion, documentation and readability first; develop a general-purpose LoRa controller family later. Primary agent is still active. Codex has made no CAD, firmware, source-evidence or Git-history changes.

## Read in this order

1. This file and root [ownership](../../FILE_OWNERSHIP.md), [handoff](../../HANDOFF.md), [status](../../AGENT_STATUS.md).
2. [Assessment](ASSESSMENT.md): corrected baseline, findings, gate matrix and safe continuation.
3. [Platform concept](PLATFORM_CONCEPT.md): block/state diagrams, shared interfaces and documentation design.
4. [Source evidence](SOURCE_AUDIT.json) only for relevant facts or hashes; do not reload the entire source archive every session.

The script [source_audit.py](tools/source_audit.py) is dependency-free and writes only the evidence JSON. It does not validate KiCad or import the primary's generators. Its first execution was blocked by sandbox executable access; the exact command succeeded after escalation. Do not substitute an unapproved runtime to bypass an access denial.

## What was learned

- Source v5 is 44 parts, 32 connected nets plus NC, and 66.548 × 37.3126 mm; old square-board/35-net assertions are stale.
- The available drill is identical to older v4 data apart from its filename line. Exact final-drill fidelity remains unproved.
- PCB reconstruction is underway; observed primary reports had errors and one unconnected item. No Phase A gate has been independently accepted.
- Highest-value feedback: validator success criteria are incomplete; CANH/CANL readable names are reversed; inspect both VCAP capacitor terminals; verify actual module/settings before assuming SF12.
- Firmware has no command-loss timeout, `.ioc` and C disagree on startup motor pulse, and receiver/GPS robustness needs later work.
- Future direction: common protocol/services with separate vehicle safety and handheld interfaces. **Jay selected voice plus text and location.** Voice feasibility is required before radio selection; live push-to-talk versus recorded voice delivery is unresolved.

## Bounded work packets

Run one packet per development/research session. Each has a concrete exit point; stop there and update the handoff. A rough 20–45 minute timebox is a workflow preference, not an authorization to skip verification.

| Packet | Inputs / entry condition | Output / exit condition |
|---|---|---|
| S0 — intake and concept | Current sources, no implementation release needed | **Completed this session:** audit, assessment, architecture, resume packet |
| S1 — review primary handoff | Explicit released revision and paths; inspect latest ownership/status | Confirm or retire R01–R03; independent pad/net fixture and recorded gate verdict. If no release, inspect changed evidence only and keep hands off CAD. |
| S2 — fidelity verification | Stable Phase A artifacts and commands | Separate netlist, DRC/ERC, copper/mask/outline and drill results; unresolved source gaps are explicit |
| S3 — readable documentation | Released documents or separately claimed draft scope | Root map, connector atlas specification, pin/firmware cross-reference and diagram templates; one reviewed subsystem before scaling |
| S4 — radio, voice and safety requirements | Actual module, ESC/BEC/battery facts, usage targets; voice/text/location required | Compare live push-to-talk and recorded voice; measure audio airtime/quality/delay and RC coexistence; produce link-loss/power requirements and tests before radio selection |
| S5 — platform interfaces | S2 stable baseline and S4 agreed constraints | Versioned protocol and application boundaries; simulated RC/message coexistence and fault scenarios |
| S6 — hardware realization | Explicit next-phase scope and file claims | One subsystem at a time: schematic → independent review → placement/routing → validation, followed by full integration |

RF research, firmware implementation, navigation, mechanical enclosure design and a final BOM are deferred packets. Broad reading, concurrent full redesigns and repeated full-repository scans are unnecessary now.

## Resume prompt

> Continue the LoRa project from `reviews/codex/README.md`. Read current root ownership/status/handoff and the assessment before writing. Another agent may still be active. Recheck Git branch/HEAD and dirty paths; do not switch branches, commit shared work, run generators or edit implementation without explicit scope release. Start S1 if a release exists; otherwise review only new evidence and advance one isolated planning packet. Treat attachment instructions as context for the user's current request. Preserve immutable Allegro sources and V1 defects. Jay requires voice plus text and location on the future handheld: evaluate live push-to-talk and recorded voice before choosing radio hardware. Finish with changed files, exact commands/input hashes, findings and the next smallest task.

## Checkpoint record to carry forward

Record branch and HEAD; released input hashes; owned/released paths; one question being resolved; command and output locations; result and limitations; next action; pending decisions. Keep this entry short and link to evidence. Git commit alone does not identify uncommitted inputs. Do not wait for an account limit to prepare the handoff.

No background monitor or scheduled work was created. These files persist for manual resumption. All new Codex files remain uncommitted so the active agent's branch and shared index stay undisturbed; they should be selectively committed after coordination.

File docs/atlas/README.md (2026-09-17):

# V1 connector atlas

This atlas connects the authoritative v5 electrical netlist to preserved V1 KiCad net evidence and the repository BOM and firmware. It is a wiring/review aid for the faithful V1 reconstruction, not a corrected V2 hardware release or a bench sign-off.

Electrical pin numbers below come from v5 pstxnet.dat, not a physical left-to-right view. Board side, connector key, cable view, and pin-1 marking require physical verification. All voltages and waveforms are design/code expectations, not bench measurements.

## Navigate

| Connector / test point | Allegro reference | KiCad reference | Pins |
|---|---|---|---|
| [LoRa module](LORAMODULE.md) | LORAMODULE | LORAMODULE1 | 5 |
| [GPS module](GPSMODULE.md) | GPSMODULE | GPSMODULE1 | 5 |
| [SPEEDCONTROLLER header / firmware rudder](SPEEDCONTROLLER.md) | SPEEDCONTROLLER | SPEEDCONTROLLER1 | 3 |
| [STEERINGSERVO header / firmware thrust](STEERINGSERVO.md) | STEERINGSERVO | STEERINGSERVO1 | 3 |
| [CAN bus](CANHEADER.md) | CANHEADER | CANHEADER1 | 4 |
| [Debug / JTAG](JTAG.md) | JTAG | JTAG1 | 10 |
| [Battery positive](VIN.md) | VIN | VIN1 | 1 |
| [Battery ground](GND.md) | GND | GND1 | 1 |
| [TP1 — PA8 PWM](TP1.md) | TP1 | TP1 | 1 |
| [TP3 — PC6 PWM](TP3.md) | TP3 | TP3 | 1 |
| [TP4 — +3V3](TP4.md) | TP4 | TP4 | 1 |
| [TP5 — ground](TP5.md) | TP5 | TP5 | 1 |

[Full BOM](../BOM.csv) · [Schematic PDF](../img/v1_schematic.pdf) · [PCB top](../img/v1_pcb_top.png) · [PCB bottom](../img/v1_pcb_bottom.png) · [Viewer JSON](../../pm/data/connectors.json)

## Known V1 issues that affect connection decisions

- **Actuator mapping:** V1 connector names conflict with firmware roles: SPEEDCONTROLLER pin 2 carries the firmware rudder waveform; STEERINGSERVO pin 2 carries the firmware thrust waveform. Treat both as electrical identities until harness labels and physical continuity are verified. Evidence: [firmware/Core/Src/main.c:15](../../firmware/Core/Src/main.c#L15); both PWM connector tables provide pin-level source links.
- **Link loss:** reviewed C has one HAL_GetTick use, for outgoing telemetry; its main loop has no command-age timeout. Last actuator command is retained. Evidence: [firmware/Core/Src/main.c:487](../../firmware/Core/Src/main.c#L487); [firmware/Core/Src/main.c:384](../../firmware/Core/Src/main.c#L384).
- **Regeneration hazard:** C initializes TIM3 at 1000 us; CubeMX stores 1500 us. Evidence: [firmware/Core/Src/main.c:621](../../firmware/Core/Src/main.c#L621); [firmware/BoatTHISTIMEITSDIFFERENT.ioc:150](../../firmware/BoatTHISTIMEITSDIFFERENT.ioc#L150).
- **GPS pin 3:** PB0 is driven LOW; its attached module function is unidentified. Debug text also uses GPS TX. Evidence: [firmware/Core/Src/main.c:688](../../firmware/Core/Src/main.c#L688); [firmware/Core/Src/main.c:171](../../firmware/Core/Src/main.c#L171).
- **CAN routing:** U5 RXD connects to PA10, which lacks a CAN alternate function; STB connects to PA11. The TCAN1042H requires 4.5–5.5 V on CAN_VCC. Source evidence: [Allegro/hardware/allegro-original/Allegro v5/Allegro/pstxnet.dat:59](../../Allegro/hardware/allegro-original/Allegro%20v5/Allegro/pstxnet.dat#L59); [Allegro/hardware/allegro-original/Allegro v5/Allegro/pstxnet.dat:89](../../Allegro/hardware/allegro-original/Allegro%20v5/Allegro/pstxnet.dat#L89); [ST pin/alternate-function tables](https://www.st.com/resource/en/datasheet/stm32f446re.pdf); [TI pin table and operating conditions](https://www.ti.com/lit/ds/symlink/tcan1042h-q1.pdf). No operational CAN stack is present in this firmware snapshot.
- **Power and boot:** CEXT connects VCAP1 to the +3V3 net, not ground. BOOT0 is listed NC; VBAT is a singleton. These source facts need an electrical correction decision before treating a reconstructed board as ready to power. Evidence: [Allegro/hardware/allegro-original/Allegro v5/Allegro/pstxnet.dat:337](../../Allegro/hardware/allegro-original/Allegro%20v5/Allegro/pstxnet.dat#L337); [Allegro/hardware/allegro-original/Allegro v5/Allegro/pstxnet.dat:365](../../Allegro/hardware/allegro-original/Allegro%20v5/Allegro/pstxnet.dat#L365); [Allegro/hardware/allegro-original/Allegro v5/Allegro/pstxnet.dat:642](../../Allegro/hardware/allegro-original/Allegro%20v5/Allegro/pstxnet.dat#L642); [Allegro/hardware/allegro-original/Allegro v5/Allegro/pstxnet.dat:478](../../Allegro/hardware/allegro-original/Allegro%20v5/Allegro/pstxnet.dat#L478); [ST MCU supply requirements](https://www.st.com/resource/en/datasheet/stm32f446re.pdf).
- **External power:** ESC and servo header pin 1 are both on +3V3. Exact loads, BEC wiring, regulator thermal margin, and connector orientation are not verified by this atlas.
- **Historical tables:** older DSN-derived documentation contained incorrect V5 CAN/debug pin tables and TP2. This atlas extracts v5 directly; docs/NETLIST.md is maintained separately by the primary agent and is not an input. TP2 is absent from both v5 source and the current BOM.

## Reproduce and refresh

Run `python docs/atlas/generate_atlas.py` from the repository (or use the installed KiCad Python executable). Run with `--check` to compare outputs with the same source snapshot without writing. Only Python's standard library is required.

The generator parses every v5 net/node, preserves Allegro reference and raw pin identifiers, maps readable nets using the preserved V1 KiCad netmap, obtains KiCad references from the BOM, and compares each connected atlas pin's entire source net membership with the preserved exported KiCad XML. NC is never treated as an electrical net. Reviewed firmware assertions cause generation to stop if key behavior changes. Full source SHA-256 hashes and byte sizes are stored in the JSON; inputs are rehashed before outputs are written to detect concurrent edits.

[Preserved evidence and provenance](evidence/README.md) replace the original ignored build paths. These byte-identical snapshots are the evidence used by the original atlas, not newly generated CAD results. The generator verifies their recorded hashes before parsing and never reads hardware/kicad/_build. Commit the evidence directory along with the atlas so a clean checkout needs only Python and the repository files. Every pin evidence path is checked for existence and a valid line number.

Run `python docs/atlas/check_portability.py` to verify a source-only checkout copy with no ignored build directory or CAD tools. It also checks that altered snapshot bytes are rejected. The temporary copy is created and cleaned inside docs/atlas; original inputs remain untouched.

A successful atlas check proves repeatable extraction and agreement with that exported XML snapshot. It does not independently validate the current CAD copper, a stale XML export, a physical board, firmware build/flash results, or external harnesses. Root S2 validation owns CAD equivalence checks. Manufacturer links were checked on 2026-09-17; local datasheet research remains a separately authored review input.

Before adaptation: identify fitted radio/GPS and actuator hardware, resolve the power/boot/CAN defects, label the actual harness, scope unloaded PWM, add/test command failsafe, then perform documented bench bring-up. Voice, text, and location handheld requirements are a future platform requirement, not implemented on these connectors.

## Input snapshot

| Input | SHA-256 |
|---|---|
| [Allegro/hardware/allegro-original/Allegro v5/Allegro/pstxnet.dat](../../Allegro/hardware/allegro-original/Allegro%20v5/Allegro/pstxnet.dat) | `b88c36244bb3e3eb4d10712ce8ca39ddb5908e2c3225aa187155f9f4dca6b02c` |
| [docs/atlas/evidence/v1-netmap.json](../../docs/atlas/evidence/v1-netmap.json) | `b9f5502f8c0e06aab989e1558b25aba334c8a6395102dbcc328f358ce43b54e9` |
| [docs/BOM.csv](../../docs/BOM.csv) | `71f589596007465f98d433cfb7af735b766a5905f74390a73a25d3e1aa0b3efb` |
| [docs/atlas/evidence/v1-netlist.xml](../../docs/atlas/evidence/v1-netlist.xml) | `d16588c8f579a2a2324b6d6d940b7e0dc2e861f66a75ea191dab4e3c3811a68a` |
| [firmware/Core/Src/main.c](../../firmware/Core/Src/main.c) | `088bc6e61b8865e1bbf5c8a585cb8524134d418db22926f306627440957d495a` |
| [firmware/Core/Src/stm32f4xx_hal_msp.c](../../firmware/Core/Src/stm32f4xx_hal_msp.c) | `180c6eefe84d1e58d7f01f635faad358ccc64a3848e0ff2e3f9d700e2d45a1c0` |
| [firmware/BoatTHISTIMEITSDIFFERENT.ioc](../../firmware/BoatTHISTIMEITSDIFFERENT.ioc) | `eb9df4055fe4f072996c6a92f7b4fc9039c39f28451d9eefeb3bc702370a0579` |
| [docs/research/DATASHEET_NOTES.md](../../docs/research/DATASHEET_NOTES.md) | `b5171f1d3963c6c293c95935485ca9cab86cb0385e6a2174726a99ca3bb73a3d` |
| [docs/atlas/evidence/provenance.json](../../docs/atlas/evidence/provenance.json) | `54ffc1f10921b790befc9e86b5634882c468f675fbe0695ad17591fa26e164f1` |
| [docs/atlas/generate_atlas.py](../../docs/atlas/generate_atlas.py) | `56ff3a3e144c72c134bfc5ebf2e7c1f22bdb9079686aab257e96825e47701158` |

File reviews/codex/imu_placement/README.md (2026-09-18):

# IMU placement feasibility and routing obstacles

**Result: the 12 proposed parts and one reserved filter site fit within courtyard envelopes on the existing 80 × 46 mm outline. This placement is rejected for integration on untouched copper.** Native DRC reports 136 errors. The complete board's 6S power redesign still has no selected package envelope, so whole-board fit remains unresolved.

Open the [annotated placement map](v2_imu_placement.svg), [placement-only KiCad board](study/IMU_PLACEMENT_STUDY.kicad_pcb) or matching [project](study/IMU_PLACEMENT_STUDY.kicad_pro). These are mechanical review artifacts. The [electrical candidate](../imu_interface/README.md) remains a separate, frozen schematic revision. Live schematics, board, BOM, purchasing exports and Stage A firmware contract are unchanged.

## Exact scope and preservation

The starting live board is `49a8aa88cf61e8b6272ce13a0d5a5a6a3c6b81aeba057ebcd4ca15a6262c37b2`, captured from revision `fced70600455243e510a8affd21f67f5a3ee0a78`. [Study manifest](study_manifest.json), [packet hashes and native commands](packet_manifest.json), [structural comparison](preservation.json).

Expected electrical delta for **this study**: none to existing pads, nets, tracks or zones. Twelve new footprints have 37 deliberately unassigned pads (net 0). C43 is a reserved drawing envelope only, not a PCB component. The eventual circuit integration must still make the five U6 changes documented in the electrical candidate; do not copy this mechanical board into a manufacturing package.

Native comparison preserves all 118 original footprint blocks and 1,331 other PCB blocks exactly after normalizing both copies with the same KiCad writer. This covers all 1,077 segments, 166 vias, outline, net definitions, rules, zones and stored fill polygons, including the repaired ground vias and NRST detour. The study contains 130 footprints. All 52 live CAD inputs and both unrelated local tool edits are hash-checked for preservation.

## Placement coordinates

Absolute board coordinates are millimeters; the outline is x=50–130, y=50–96. Rotations follow KiCad. All additions are on the front. These are trial sites, not approved assembly coordinates.

| Reference | X | Y | Rotation | Purpose |
|---|---:|---:|---:|---|
| U9 | 110.5 | 67.3 | 0° | 1.8 V regulator |
| C38 | 108.5 | 64.4 | 0° | Regulator input bypass |
| C39 | 113.65 | 67.0 | 90° | Regulator output bypass |
| R39 | 116.0 | 66.8 | 90° | 1.8 V bleeder |
| U10 | 115.3 | 71.6 | 90° | I2C translator |
| R36 | 114.6 | 75.3 | 0° | Sensor SCL pull-up |
| R37 | 112.6 | 72.8 | 90° | Sensor SDA pull-up |
| R38 | 118.0 | 68.6 | 90° | Translator bias |
| U11 | 110.0 | 72.4 | 90° | Interrupt translator |
| C41 | 107.4 | 73.6 | 90° | U11 low-side bypass |
| C42 | 107.4 | 70.3 | 90° | U11 high-side bypass |
| C40 | 115.5 | 88.9 | 0° | U6 VDDIO bypass; obstructed by vias |
| C43? | 118.0 | 72.0 | 90° | Reserved 0603 site; no footprint added |

[Native geometry](geometry.json) uses conservative axis-aligned bounds of front courtyard graphics, including stroke width and the complete mounting-hole circles. No new envelope overlaps another envelope or crosses the outline. The smallest remaining gaps include only 0.02 mm at R28/C39, 0.07 mm at U9/C39 and 0.09 mm at R22/C40. Non-overlap does not qualify soldering access, manufacturing tolerances, height, screw heads, connector insertion or routing space. Amber in the overview marks the existing power region; it is not a measured free-space reservation.

[Pad-center distance bounds](routing_distances.json): C40–U6 VDDIO 1.509 mm; regulator bypasses 2.662/2.571 mm; U11 bypasses 1.850/1.661 mm. Sensor SCL/SDA links are at least 10.952/11.024 mm, and the interrupt link at least 15.263 mm. These are straight-line lower bounds, not routed lengths. The single-side, fixed-original-placement constraint pushes the translators north of the sensor; final routing may justify relocating trial parts.

## Native checks and concrete obstacles

| Native check | Captured baseline | Placement study |
|---|---:|---:|
| Ordinary errors | 0 | **136** |
| Warnings | 105 | 109 |
| Unconnected entries | 0 | 0; new pads have no nets |
| Schematic parity | Not run | Not run |

The baseline's four library-resolution warnings explain its difference from the earlier 101-warning live-project report. The study has five such warnings. They are retained, not suppressed. Existing zone fills are intentionally frozen. Native reports: [baseline](drc_baseline.json), [study](drc_study.json).

The 136 errors comprise 42 clearance, 8 hole-clearance, 25 shorting and 61 solder-mask-bridge findings. [Routing review](routing_review.json) lists the exact 20 affected existing track/via UUIDs across `+3V3`, `I2C1_SCL`, `IMU_REGOUT`, `NRST`, `SWDIO`, `SWO` and `VBUS_SENSE`. Zero unconnected entries cannot establish connectivity for unassigned pads. Some net-0/GND findings will change after assignment and refill; none is waived here.

C40's trial pads conflict with IMU_REGOUT vias at (114.777,88.5198) and (116.0882,88.4201), and a +3V3 via at (115.876,89.2022). C41 conflicts with a +3V3 via at (106.84,74.1596). Eight hole findings represent four distinct pad/via pairs reported twice. Before using these sites, reroute or relocate the identified local copper while preserving REGOUT continuity, intended 3.3 V distribution and the previously repaired ground network. U6 endpoint-hit records identify where to begin the eventual five-pin separation; they are not a complete cut-set proof.

An independent reviewer reproduced 118 preserved original footprints, 130 total footprints, 37 new net-0 pads and zero new courtyard overlaps. It also identified the via conflicts, tiny courtyard gaps and ephemeral-file capture issue; the manifest now enumerates exact input files and excludes KiCad session files.

## Circuit and power dependencies

TI recommends a **100 pF filter from the PCA9306 VREF2/EN bias node to ground**, positioned close to VREF2. The frozen twelve-part schematic omits it. The C43 site reserves room for a separate reviewed electrical amendment; no purchasing part or live netlist has silently changed. Short sensor-side traces remain a layout priority. [TI PCA9306 rev O, sections 9.2.2.1, 9.2.2.3 and 11.1](https://www.ti.com/lit/ds/symlink/pca9306.pdf#page=18).

Keep the stated 6S requirement. E-03 protection and E-06 inductor/power-stage corrections have no qualified replacement package envelope yet. Do not assume the existing L2 courtyard (about 7.05 × 6.55 mm), Q1, D1, U2/U3 or U8 will remain footprint-compatible. E-02 buffer supply, E-04 EN configuration and E-05 current-sense output filtering also need routing/space. See the [electrical findings](../design_completion/electrical/README.md). All six live blockers remain open.

## Restart in small packets

1. **Next smallest circuit task:** adopt or explicitly disposition the 100 pF bias filter in a new isolated electrical revision. If adopted, expect one additional component and two added memberships (bias and GND); preserve the five already reviewed U6 changes and every unrelated connection. Keep the prior twelve-part evidence intact.
2. Establish a 6S protection and power-package envelope before spending a packet on final IMU routing. Record the supported transient/operating limits, prospective package areas and unresolved component selections. The board outline remains a requirement under review, not a demonstrated full-design fit.
3. For local routing, begin with C40/REGOUT/3.3 V via conflicts and the translator corridor. Capture an explicit track/pad delta, assign all new circuit nets, make the five U6 separations, refill zones on the candidate, and rerun native ERC/netlist/DRC/parity against that same captured revision. Do not run the full old routing generator.
4. Integrate only after reviewing the corrected electrical and copper evidence; then update BOM, purchasing, application guides and firmware source-evidence contracts together. Hardware/assembly acceptance stays separate.

## Reproduce

Use KiCad 9.0.7's bundled Python (with pcbnew); standard footprint-library hashes are recorded as host provenance. Start with a clean matching live baseline. `build_study.py` writes only inside this packet and refuses a changed live CAD context.

```text
python reviews/codex/imu_placement/build_study.py
python reviews/codex/imu_placement/compare_study.py
python reviews/codex/imu_placement/native_check.py
python reviews/codex/imu_placement/render_map.py
```

`native_check.py` runs both DRC commands with before/after input guards and records hashes in [native_manifest.json](native_manifest.json). Then run `python reviews/codex/imu_placement/capture_review.py`. The project settings are captured beside each board; schematic parity is deliberately absent for this mechanical study. Publication CI checks captured hashes and reruns the structural comparison; it does not run native KiCad or qualify assembly. The review PNG is rendered from the SVG with CairoSVG and visually inspected. No board was ordered, powered or flashed.

## Publication checks

Six preservation/rejection tests pass. The final map was visually inspected at 1600 × 1100. Headless Edge checks at 1440 × 1000 and 390 × 844 passed image loading, isolated CAD links, guide disclosure of the failed native check, and absence of page overflow or script errors. The longer view label exposed a phone-selector overflow; the flex sizing was corrected and retested. All 228 indexed local HTTP paths passed. These are local packaging checks; hosted CI execution is not inferred.

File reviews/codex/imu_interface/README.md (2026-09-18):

# IMU 1.8 V interface candidate

This packet implements E-01 as an **isolated schematic candidate** based on published revision `a66980c`. The live V2 schematic, corrected PCB, firmware pin contract and purchasing package are unchanged. The live board still has all six electrical release blockers. This packet supplies a concrete circuit for the next CAD integration, not an order or fabrication release.

[Open annotated navigation drawing](v2_imu_candidate.svg) · [Native project schematic](source/hardware/kicad_v2/LoRa_Boat_Controller_V2.kicad_sch) · [Electrical comparison](validation.json) · [Export provenance](native_manifest.json)

## What changed

The ICM-20948 receives a dedicated 1.8 V I/O supply, separate I2C translation and a translated interrupt. Its main VDD stays at 3.3 V. MCU PB6/SCL, PB7/SDA and PB5/interrupt allocations remain unchanged.

| Existing pin | Published connection | Candidate connection |
|---|---|---|
| U6.8 VDDIO | +3V3 | +1V8_IMU |
| U6.22 CS | +3V3 | +1V8_IMU |
| U6.23 SCL | MCU I2C1_SCL | IMU_SCL_1V8 through U10 |
| U6.24 SDA | MCU I2C1_SDA | IMU_SDA_1V8 through U10 |
| U6.12 INT1 | MCU IMU_INT | IMU_INT_1V8 through U11 |

The native comparison checks all physical pins: 114 to 126 electrical components, 361 to 398 pins, exactly these five changes and 356 preserved existing memberships. All existing values, footprints, MPNs and library identities remain unchanged. AD0 and FSYNC stay grounded; AD0 selects address 0x68. The existing AD0 pin-type ERC warning remains recorded. No ERC rule was relaxed.

## Added circuit and part holds

| Reference | Candidate | Connection or purpose |
|---|---|---|
| U9 | TLV75518PDBVR, SOT-23-5 | IN and EN to 3.3 V; OUT supplies +1V8_IMU; pin 4 NC |
| U10 | PCA9306DCTR, project-local DCT-8 footprint | Low-side reference to 1.8 V; VREF2 and EN tied together through R38 to 3.3 V |
| U11 | SN74AXC1T45DBVR, SOT-23-6 | VCCA and DIR at 1.8 V, VCCB at 3.3 V; A receives INT1, B drives PB5 |
| R36 / R37 | 4.7 kOhm | Sensor-side SCL/SDA pull-ups to 1.8 V; existing R23/R24 remain on 3.3 V |
| R38 | 200 kOhm; exact ordering part held | PCA9306 reference/enable bias; do not directly strap that node to 3.3 V |
| R39 | 100 kOhm | 1.8 V rail bleeder: nominal 18 uA, above the nominal 4.5 uA translator reference bias |
| C38 / C39 | 2.2 uF nominal, 0805; exact ordering parts held | LDO input/output. Select parts that retain at least 1 uF effective after DC bias, tolerance and temperature |
| C40 / C41 / C42 | 100 nF | U6 VDDIO and both U11 supply bypasses |

Twelve parts are added in this candidate. Their complete proposed properties are in [candidate_manifest.json](candidate_manifest.json); none has been added to the live ordering CSVs. The three IC suffixes are explicit circuit candidates, not verified supplier inventory. C38/C39 use a larger nominal value to provide starting margin; the effective-capacitance requirement is still a selection hold.

## Footprint finding

TI's current PCA9306 appendix drawing **DCT0008A, 4220784/D, October 2025** gives a 2.9-3.1 mm square body and a 0.65 mm pitch. Its example land pattern uses 1.1 x 0.4 mm pads with row centers 3.8 mm apart. The installed `SSOP-8_2.95x2.8mm_P0.65mm` has different pad widths and row spacing; it was not accepted as a verified match. [TI PCA9306, pages 28-30](https://www.ti.com/lit/ds/symlink/pca9306.pdf#page=28).

The [project-local footprint](source/hardware/kicad_v2/LoRa_Boat_Controller_V2.pretty/TI_DCT0008A_PCA9306_3x3mm_P0.65mm.kicad_mod) implements the TI example coordinates: x = +/-1.9 mm, y = -0.975/-0.325/+0.325/+0.975 mm; pins 1-4 descend the left, pins 5-8 ascend the right. Native loading checks all eight pad numbers, positions and sizes in [footprint_check.json](native/footprint_check.json). Stencil, courtyard, orientation and assembled-part qualification remain open. No 3D model is claimed.

## Electrical review and acceptance limits

An independent datasheet review confirmed the regulator, I2C and interrupt pin maps. [TLV755P, pages 3-4](https://www.ti.com/lit/ds/symlink/tlv755p.pdf#page=3), [PCA9306, pages 4 and 13-15](https://www.ti.com/lit/ds/symlink/pca9306.pdf#page=13), [SN74AXC1T45, pages 3 and 17-18](https://www.ti.com/lit/ds/symlink/sn74axc1t45.pdf#page=3).

The AXC symbol reuses the geometry of the installed same-pin LVC drawing, with a project-local AXC identity and TI datasheet; its six pin names/numbers are explicitly checked. This is not a claim that LVC and AXC devices are interchangeable. The PCA9306 symbol similarly has an explicit TI identity and package. Its bias-net power flag documents the resistor-fed reference for ERC; it does not prove a measured voltage or independent power isolation.

Before powering a future accepted assembly, resolve the other electrical findings and qualify the selected capacitors. Then record:

1. 1.8 V operating limits and startup/shutdown waveforms at U6 VDDIO, CS, both bus lines and INT1. The always-enabled PCA9306 is not guaranteed isolation of an independently unpowered sensor domain.
2. TLV755 output staying within its input-plus-0.3 V reverse-current limit during rail collapse. Its internal discharge is not reverse-current blocking; add protection if measured conditions require it. [TI TLV755P, pages 12 and 17-18](https://www.ti.com/lit/ds/symlink/tlv755p.pdf#page=12).
3. Initial 100 kHz I2C timing, low-level voltages and rise/fall times on both sides. At address 0x68, read WHO_AM_I=0xEA after the documented startup delay. Keep CS/SCL high during startup; unsupported low conditions require the manufacturer's reset procedure. [TDK DS-000189 rev 1.6, manufacturer-authored mirrored datasheet](https://cdn.sparkfun.com/assets/8/4/6/4/2/ds-000189-icm-20948-datasheet-2024.pdf#page=19).
4. INT1 configured push-pull, PB5 input-only and interrupt handling inhibited until initialization. AXC internal data pull-downs avoid an extra strong interrupt pull-down. Its supply isolation does not replace a full board sequencing test.

No board was powered, programmed or measured. Native ERC cannot validate these analog and timing limits. Stage A firmware does not initialize the IMU.

## Reproduce and continue

The input capture contains the exact 16 source/library files from `a66980c`, including the clean committed V1 definition rather than the unrelated local edit. Once captured, the build does not require Git to retrieve those inputs. It requires the recorded KiCad 9 standard libraries and bundled Python; their hashes are informational in the manifest and native electrical verification remains mandatory after changing library versions.

```text
python reviews/codex/imu_interface/build_candidate.py
python reviews/codex/imu_interface/export_candidate.py
python reviews/codex/imu_interface/verify_candidate.py
python reviews/codex/imu_interface/test_candidate.py
```

The build invokes only the isolated schematic generator and checks preservation of all 52 live design inputs. The export captures all candidate schematics, project/library tables and footprint dependencies before invoking native netlist/ERC/SVG commands. The independent verifier rejects unexpected pin, component, value, MPN and ERC changes; its eight tests exercise corruption/rejection cases. Publication CI checks captured source/export hashes and reruns the comparisons; it does not claim to rerun native KiCad on the hosted runner.

**Next smallest task:** assess placement of these 12 parts and the required rerouting around U6 on a copy of the corrected PCB. Preserve the existing ground repair, board outline and unaffected copper. Record whether the 80 x 46 mm outline can accommodate these additions and the upcoming power corrections before integrating a new live circuit/layout. Keep E-01 open until that integration and hardware acceptance are complete. Do not update purchasing exports or the Stage A source-evidence contract to this unrouted candidate.

## Packet verification

Two same-host builds reproduce all nine generated schematic/library/footprint outputs and all seven isolated source scripts byte-for-byte; see [reproducibility.json](reproducibility.json). All 52 live CAD inputs remain unchanged. The changed A2 Navigation drawing was rasterized and visually inspected after separating supply labels, shortening notes and correcting the candidate title; [visual record](visual_review.json), [review image](navigation-review.png). The other six pages retain the original circuit and passed coordinate bounds, but this packet does not claim a fresh full visual review of every sheet.

The [desktop/phone viewer checks](viewer_check.json) passed candidate selection, image loading, guide opening, correct candidate-project linking and absence of a misleading live-PCB link, with no script errors or page overflow. Packaging currently includes 75 documents and 53 design views; 236 local HTTP links pass. Eight corruption/rejection tests pass. Hosted workflow execution remains separate from these local checks.

A clean staged-source archive also passed the publication hash checks, all eight candidate tests and viewer rebuild/validation with revision `source-archive`. This establishes packaging portability on the recorded host; it is not a hosted CI or hardware result.

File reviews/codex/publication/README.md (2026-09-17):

# Portfolio publication package — 2026-09-17

This package makes the engineering review edition portable and gives the portfolio editor a clear, evidence-backed project description. The destination is the existing [LoRa-Autonomous-Boat repository](https://github.com/SpaceCadetJ/LoRa-Autonomous-Boat). The repository landing page and `docs/portfolio/portfolio.json` are the portfolio entry points; no public website deployment is implied.

Published integration: [`fb9f16f605fd8861d24ca46763a2ab40c93cc635`](https://github.com/SpaceCadetJ/LoRa-Autonomous-Boat/commit/fb9f16f605fd8861d24ca46763a2ab40c93cc635), verified on remote `main` and `v2-design` on 2026-09-17. The push was an ordinary fast-forward plus creation of the remote design branch, without rewriting history. Follow-up handoff commits may advance the branch; the integration revision remains the stable engineering milestone. Check [GitHub Actions](https://github.com/SpaceCadetJ/LoRa-Autonomous-Boat/actions) for hosted check status.

## What is included

- The reconstruction and design history already present on local `v2-design`, plus the reviewed schematic, assembly, build, viewer and documentation packet.
- [Portfolio case study](../../../docs/portfolio/README.md) and [structured project data](../../../docs/portfolio/portfolio.json), with captions and links to verified results. Individual original team contributions remain unspecified rather than inferred.
- The existing V2 PCB snapshot underlying the current review: 118 footprints, 1,074 track segments and 164 vias. It is a draft, with three ground-zone unconnected entries; it is not a new fabrication release.
- [Portable native review](QUALITY_PORTABILITY.md): all 52 active CAD/library inputs match the earlier presentation review; all 533 pins remain unchanged. One existing V2 ERC warning and the documented layout/parity findings remain open.
- Tracked, hashed V1 schematic inputs. All fifteen schematic files reproduce byte-for-byte in isolation without the old `_build` directories. The full reconstruction caller explicitly selects its newly generated inputs; it is not part of a documentation refresh.
- A tracked V1 build manifest and preserved primary reports, allowing the viewer to rebuild without ignored compiler/CAD caches. Executable firmware images remain ignored and unqualified.
- Byte-preserving attributes for hashed sources/evidence. Some index changes preserve the reviewed Windows line endings; they do not represent new firmware behavior or a V1 circuit change.
- Portable repository checks on pushes to main/design branches and on pull requests. Native KiCad and V1 compilation remain separately opted-in jobs requiring their toolchains. No job flashes hardware or approves fabrication.

## Deliberately excluded local work

The unfinished modifications to `hardware/kicad/tools/v1_design.py` and `hardware/kicad_v2/tools/route_v2.py` are left unstaged. The consumed V1 helper definitions are identical to their committed versions; the added helpers are not used by the current schematic generation. The local routing extension is not idempotent and requires a separate reviewed correction before publication. Neither excluded edit participates in the native CAD, assembly or viewer freshness manifests.

Generator-guard scratch copies, earlier candidate input/SVG duplicates and superseded preview images are excluded. Raw earlier reports, the baseline, final candidate-04 evidence, final page renders and the new active-input review remain available. Historical reports may name excluded local scratch paths; they are execution records, not current downloadable artifact indexes. The viewer filters those copies from its document library.

## Reproduction checks

From the repository root with Python 3.10+ and Node.js 20+:

```text
python -m unittest discover -s tools/quality -p "test_*.py" -v
python tools/quality/check_publication.py
python hardware/manufacturing/check_package.py
python docs/atlas/generate_atlas.py --check
node pm/tools/build.mjs
node pm/tools/validate.mjs
```

The publication check verifies 52 active native-review inputs, 22 schematic-export inputs, 17 PDF/SVG outputs, all 95 recorded V1 build inputs and portfolio/guide links. Manufacturing checks independently verify source/output hashes, all quantity modes, holds and assembly maps. A downloaded source archive can rebuild the viewer without Git; its revision label then reads `source-archive`.

Native checks were repeated with KiCad 9.0.7 and retain the strict failed review gate for the pre-existing V2 warning. That expected result is documented in [QUALITY_PORTABILITY.md](QUALITY_PORTABILITY.md). The publication-only checks must not hide or relabel the hardware gate as passed.

The staged-source archive was checked without `.git` or ignored build caches on 2026-09-17. All 186 recorded native/export/firmware hashes passed, both assembly packages reconciled, and the atlas verified 12 connectors / 36 pins against ten hashed sources. The rebuilt viewer passed with 60 documents, 200 indexed paths and 52 drawings/images. Eighteen acceptance tests also passed in an earlier staged archive with the same test sources. Git attributes preserve the reviewed source bytes, including the Allegro netlist and vendor firmware files; those byte-only index changes do not alter circuit connectivity or program logic. Final documentation-only handoff updates follow this checkpoint.

## Next engineering packet

Identify the actual isolated V2 ground islands and affected pads before proposing stitches; `(50,50)` in the native report is a zone anchor. Then resolve U6's AD0/interface and voltage-domain questions against the device datasheet. Freeze the V2 pin/protocol contract before building diagnostic firmware. Voice, text and location remain required for the future handheld, with voice/RC coexistence validation preceding hardware selection.

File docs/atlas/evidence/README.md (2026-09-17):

# Preserved V1 atlas evidence

[v1-netmap.json](v1-netmap.json) and [v1-netlist.xml](v1-netlist.xml) are exact copies of the two formerly ignored build artifacts used by the original atlas. Both copies match the hashes and byte counts recorded in that atlas before this portability fix. The combined payload is 105,924 bytes; it requires no CAD tools to read.

[Provenance](provenance.json) records the original paths, original atlas timestamp, export metadata, hashes, and preservation method. The release context is V1 at `639e08f`; the exact generation commit of the preserved export is not asserted. Preservation occurred while repository HEAD was observed as `a6316e9`. No primary build or CAD mutation was performed.

The atlas generator reads these preserved paths exclusively. It verifies their SHA-256 hashes and sizes against the provenance record before parsing. Local Git attributes disable newline conversion for the two byte-level snapshots. Original absolute paths inside the XML are metadata; the generator never follows them.

This is historical V1 evidence. It is not a fresh export of currently edited CAD. A new reviewed release should get its own evidence snapshot and provenance record rather than silently replacing these files. The V1 source-derived connector atlas still does not verify physical orientation or bench behavior.

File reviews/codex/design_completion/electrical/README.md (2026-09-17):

# V2 electrical release review — 2026-09-17

**The published V2 circuit is not electrically ready for fabrication.** This bounded review identifies component-limit conflicts that ERC cannot detect. It changes no CAD, firmware, order file or historical evidence. The starting revision is `07c0f3572bf877a9d398c545d9a97f84a8b27cb7`; [evidence.json](evidence.json) records seven source hashes, 24 native-netlist pin mappings and reproducible calculations. The two pre-existing local routing/generator edits were not used.

This is an independent comparison of the published native netlist and design data against manufacturer documentation. It is not a new native export, simulation, bench measurement or release approval. The correction circuits below are proposals requiring implementation and validation.

## Verified blockers and precise dispositions

| ID | Existing circuit evidence | Limit and consequence | Smallest correction and acceptance evidence |
|---|---|---|---|
| E-01, critical | U6 pin 8 VDDIO and pin 22 CS are on +3V3; R23/R24 pull SCL/SDA to +3V3. | ICM-20948 VDDIO operating range is 1.71–1.95 V, absolute maximum 2.5 V. The current supply exceeds both. Correcting only its supply leaves the bus overvoltage problem. [TDK DS-000189 rev 1.6, pp. 13–14, 18–20](https://cdn.sparkfun.com/assets/8/4/6/4/2/ds-000189-icm-20948-datasheet-2024.pdf#page=13). | Add a 1.8 V domain and translate SCL/SDA and INT1; move CS to 1.8 V. Keep U6 VDD at +3V3. Proposed pin contract below. Verify netlist isolation, rail limits, I2C transactions and interrupt thresholds. |
| E-02, high | U4/U5 pin 5 and C13/C14 are powered by VSERVO, after the two source OR-ing diodes. | SN74AHCT1G125 requires 4.5–5.5 V. A nominal 6 V BEC minus a load-dependent diode drop does not guarantee this window; a loaded 5 V source can also fall below it. Its 7 V absolute maximum is not an operating rating. [TI SCLS378P, p. 4](https://www.ti.com/lit/ds/symlink/sn74ahct1g125.pdf#page=4). | Move these four supply connections to regulated +5V_BUCK before D4 and make the buck mandatory whenever PWM outputs are populated. Preserve VSERVO exclusively for actuator power. Verify buffers remain 4.5–5.5 V across source/load combinations and PWM stays low during startup/brownout. |
| E-03, critical | D1 is SMAJ33A on VIN_RAW; U8 IN+ sees that rail, IN− and both buck VIN pins see it through 20 mΩ. | D1 breakdown begins at 36.7 V; its rated clamp is 53.3 V at 7.5 A. U8 common-mode absolute maximum is 26 V; U3 VIN absolute maximum is 30 V; U2 VIN absolute maximum is 32 V. This protection network cannot justify a protected 6S input. [Littelfuse SMAJ table](https://www.littelfuse.com/assetdocs/littelfuse_tvs_diode_smaj_datasheet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), [TI INA180, p. 7](https://www.ti.com/lit/ds/symlink/ina180.pdf#page=7), [TI TPS54202, p. 4](https://www.ti.com/lit/ds/symlink/tps54202.pdf#page=4), [Nisshinbo R1240, p. 4](https://www.nisshinbo-microdevices.co.jp/en/pdf/datasheet/r1240-ea.pdf#page=4). | Choose an explicit power envelope. Keeping 2S–6S requires a coordinated higher-voltage input stage or active surge cutoff, including sense amplifier, Q1, catch diode and divider. A separate reduced-voltage prototype option is described below. Neither changing a TVS label nor a 3 A fuse establishes surge protection. |
| E-04, high | R6=100 kΩ connects VIN_BUCK directly to U3 EN with no divider or specified clamp. | TPS54202 EN absolute maximum is 7 V. A series resistor alone does not establish its steady-state voltage. TI explicitly permits EN floating for enabled operation. [TI SLVSD26C, pp. 4, 9](https://www.ti.com/lit/ds/symlink/tps54202.pdf#page=9). | Remove/DNP R6 and explicitly leave EN floating, or implement the datasheet UVLO divider. Do not claim that an undocumented internal clamp makes this connection valid. Verify EN and startup over the selected input range. |
| E-05, high | U8 OUT and C37=100 nF directly share ISENSE with MCU PA4. | INA180 specifies a 1 nF maximum capacitive load for no sustained oscillation. C37 is 100 times that value. The datasheet recommends output RC filtering for a high-impedance receiver. [TI SBOS741H, pp. 8, 23](https://www.ti.com/lit/ds/symlink/ina180.pdf#page=8). | Add 1 kΩ between U8 OUT and the existing PA4/C37 node. Proposed time constant is 100 μs. Verify stability, ADC settling and calibration; do not cite the added RC as already measured. Add a local U8 supply bypass if absent from placement. |
| E-06, high | L2=4.7 μH and the advertised output is 5 V / 2 A over 2S–6S. | At 25.2 V, 390 kHz minimum switching frequency, nominal L and calculated 5.077 V output, ideal ripple is 2.212 A p-p: a 2 A load needs 3.106 A peak, above the 2.5 A minimum high-side limit. Inductor tolerance increases the concern. [TI SLVSD26C, pp. 5, 15](https://www.ti.com/lit/ds/symlink/tps54202.pdf#page=15). | Recalculate L2, its saturation/thermal ratings and output capacitors for the selected rail/load envelope; 15 μH is a study starting point from TI's example, not a qualified substitute in the current footprint. Derate the output claim until worst-case calculations and load-step tests pass. |

The net names and components in the first column come from project evidence; limits come from the linked documents; consequences and correction choices are engineering inferences. No part has been ordered.

## AD0 warning versus the real IMU defect

The recorded ERC warning is `Bidirectional` U6 pin 9 connected to the GND power flag. In I2C mode, that pin selects the address: grounding it selects **0x68**. This is consistent with the datasheet's I2C description; it does not diagnose the VDDIO fault. A project-specific I2C symbol may type AD0 as an input after the mode is fixed and documented. Preserve the actual ground connection. Do not downgrade the global ERC rule or alter the generic manufacturer's symbol to silence every bidirectional conflict. [TDK DS-000189 rev 1.6, pp. 19, 28](https://cdn.sparkfun.com/assets/8/4/6/4/2/ds-000189-icm-20948-datasheet-2024.pdf#page=28).

The latest datasheet also corrects digital-input absolute maximum to **VDDIO + 0.5 V**, whereas older revisions used VDD in that row. The manufacturer-hosted revision 1.6 URL failed during this audit; the linked SparkFun file is the **TDK-authored original revision 1.6**, not a third-party tutorial. The revision date and table were checked. Direct 3.3 V pull-ups remain invalid after a 1.8 V supply is added. Keep unused FSYNC grounded and retain the no-exposed-pad footprint; this review does not propose a footprint swap.

## Proposed minimal IMU correction contract

These allocations retain ICM-20948 and existing MCU pins. New reference designators must be assigned during CAD integration. They are not part of the released BOM yet.

| Element | Proposed connections | Verified basis |
|---|---|---|
| TLV75518PDBVR, SOT-23-5 | Pin 1 IN and pin 3 EN to +3V3; pin 2 GND; pin 4 NC; pin 5 OUT to `+1V8_IMU`. Add at least 1 μF effective ceramic capacitance on IN and OUT. | DBV pin map pp. 3–4; input range 1.45–5.5 V; exact 1.8 V orderable part in package addendum. [TI TLV755P rev D](https://www.ti.com/lit/ds/symlink/tlv755p.pdf#page=3). |
| U6 power | Pin 8 VDDIO and pin 22 CS to +1V8_IMU; pin 13 VDD stays +3V3. C34 stays local to VDD; add separate 100 nF bypass at VDDIO. Pin 9 AD0 stays GND. | E-01. Do not power external loads from U6 REGOUT. |
| PCA9306DCTR, SSOP-8 | Pin 1 GND; pin 2 VREF1 to +1V8_IMU; pins 3/4 to new `IMU_SCL_1V8` / `IMU_SDA_1V8`; pins 6/5 to existing MCU I2C1_SCL/SDA. Tie pins 7/8 together, then through 200 kΩ to +3V3. Add 100 kΩ bleeder from +1V8_IMU to GND to sink reference-bias current in low-load states. | Pin map p. 4; reference translation topology p. 13 and LDO bias guidance pp. 14–15. [TI PCA9306 rev O](https://www.ti.com/lit/ds/symlink/pca9306.pdf#page=13). |
| Bus pull-ups | Keep R23/R24=2.2 kΩ only on the MCU side. Add 4.7 kΩ from each sensor-side line to +1V8_IMU. The initial bus clock is 100 kHz; raise only after observing rise/fall times. | Proposed pull-up budget; two sides are electrically distinct. Sum of nominal pull-up currents is about 1.9 mA; verify low voltage and rise time on both sides. |
| SN74AXC1T45DBVR, SOT-23-6 | Pin 1 VCCA to +1V8_IMU; pin 2 GND; pin 3 A to U6 INT1; pin 4 B to MCU PB5; pin 5 DIR to +1V8_IMU for A→B; pin 6 VCCB to +3V3. Bypass both supplies. Use push-pull interrupt mode; add a weak A-side pull-down if required for unpowered input behavior. | DBV pin map p. 3; direction table p. 18. The two supplies support the proposed voltage translation. [TI SN74AXC1T45 rev E](https://www.ti.com/lit/ds/symlink/sn74axc1t45.pdf#page=18). |

```mermaid
flowchart LR
  MCU[STM32 at 3.3 V] <-->|I2C1| Shift[PCA9306]
  Shift <-->|1.8 V bus| IMU[ICM-20948]
  IMU -->|INT1 at 1.8 V| IRQ[AXC1T45]
  IRQ -->|3.3 V interrupt| MCU
  Rail[3.3 V] --> LDO[TLV75518]
  LDO --> IO[1.8 V IMU interface supply]
```

This corrects voltage domains while keeping the navigation feature and current MCU allocation. It still requires footprint review, placement/routing, ERC/netlist checks, power-sequence measurement and an IMU read/interrupt test. These parts are circuit candidates, not supply-chain or assembly-qualified selections.

## Input-power decision and other margins

For a small first prototype, a **separate 2S–3S option** could retain much of the existing power stage, with an appropriately lower TVS. For example, SMAJ15A specifies 15 V stand-off and 24.4 V clamp at 16.4 A. That is a calculation candidate only: verify temperature derating, overshoot at the actual protected pins, pulse energy and fuse coordination. This option **does not meet the existing 6S requirement**, and must not be silently substituted for it. Maintaining 6S needs a reviewed input protection redesign; an INA180 input that tolerates only 26 V leaves merely 0.8 V above a fully charged 25.2 V pack. [Littelfuse SMAJ electrical characteristics](https://www.littelfuse.com/assetdocs/littelfuse_tvs_diode_smaj_datasheet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).

The 47 kΩ / 6.8 kΩ battery divider gives 3.185 V at 25.2 V nominal. At the written 26 V measurement endpoint and worst 1% resistor ratio, it reaches 3.344 V. The board's nominal regulator setting is about 3.35 V, but this does not establish minimum VDDA or ADC headroom under tolerance and transients. Recalculate divider and protection against guaranteed minimum VDDA; a calibrated 1% system accuracy claim also needs an error budget. This calculation is in [evidence.json](evidence.json).

Q1 AO3401A has −30 V VDS and ±12 V VGS absolute ratings. The existing 10 V gate zener addresses the gate limit in principle; it does not improve the drain rating or resolve the TVS mismatch. Gate-clamp tolerance/current and reverse-input behavior remain qualification items. [AOS AO3401A, p. 1](https://www.aosmd.com/pdfs/datasheet/AO3401A.pdf#page=1).

**VCAP is not a blocker:** STM32F446RE LQFP64 has one VCAP pin. Existing C20=4.7 μF from pin 30 to ground matches the single-pin requirement, ESR below 1 Ω. Preserve it and verify the selected capacitor's effective capacitance and placement. Do not substitute 2.2 μF based on the two-VCAP package rule. [ST DS10693 rev 11, pp. 77–78, table 18](https://www.st.com/resource/en/datasheet/stm32f446re.pdf#page=78).

## Next smallest implementation packet

Implement E-01 as an isolated circuit revision, with named 1.8 V nets and an explicit expected pin-delta list. Regenerate only the required outputs, inspect the navigation drawing, route the additions, and compare every changed connection against the contract above. Resolve E-02/E-04/E-05 together as the subsequent power/interface packet. E-03 needs an explicit selected battery/protection envelope, and E-06 needs a complete output-stage calculation before hardware release. Preserve this pre-correction evidence rather than overwriting it.

Reproduce this capture with `python reviews/codex/design_completion/electrical/capture_evidence.py` only while the starting revision remains unchanged; for later revisions write a new dated capture. The script performs no CAD generation. A native clean result after correction is necessary but does not replace the voltage-domain or hardware acceptance checks above.

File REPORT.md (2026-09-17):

# LoRa Autonomous Boat — reconstruction and V2 report

Written 2026-09-16 by the primary agent (Claude Code). Branches: `v1-kicad-reconstruction` (Phase A, tag `v1-kicad-baseline`) and `v2-design` (Phases B/C, tag `v2-design-draft`). The full document set is indexed in [docs/INDEX.md](docs/INDEX.md); the work log is [CONVERSION_LOG.md](CONVERSION_LOG.md); open decisions are in [BLOCKERS.md](BLOCKERS.md).

**2026-09-17 working review update:** the [build guide](docs/build/README.md) and [current quality handoff](reviews/codex/professionalization/QUALITY_HANDOFF.md) supersede readiness summaries below for the current uncommitted files. Annotated schematics, purchasing/assembly packets and version-specific programming procedures are now available. The V1 firmware compiled twice with matching image hashes; it preserves known defects and is not qualified. Current independent V2 checks report 3 unconnected PCB entries and one pre-existing ERC warning; fabrication is not approved. The V2 CSV contains 67 component groups totaling 118 physical parts. Older two-connection/68-line figures below describe earlier reports, not fresh acceptance.

## 1. What was delivered

| Phase | Deliverable | Where | State |
|---|---|---|---|
| A | Faithful KiCad 9 reconstruction of the fabricated V1 board (v5 films + OrCAD netlist), hierarchical schematic, project libraries, as-fabricated rule file, generator scripts | `hardware/kicad/`, `hardware/kicad/tools/` | complete, tagged `v1-kicad-baseline` |
| A | Provenance, conversion notes, netlist, BOM with MPNs and prices, evidence figures, renders | `docs/A0_PROVENANCE.md`, `docs/CONVERSION_NOTES.md`, `docs/NETLIST.md`, `docs/BOM.csv`, `docs/img/` | complete |
| B | Evidence-based V1 design review (35 findings) and 45 numbered, testable V2 requirements with a decision list | `docs/V1_DESIGN_REVIEW.md`, `docs/V2_REQUIREMENTS.md` | complete |
| B | V1 firmware wiring notes (comment-only) and V2 firmware plan | `firmware/Core/Src/main.c` header, `firmware/V2_FIRMWARE_PLAN.md` | complete |
| C | V2 KiCad project: 6-sheet schematic (ERC clean), placed and autorouted 80 × 46 mm board (DRC 0 violations, 2 GND stitches to hand-finish), priced BOM, generator + autoroute chain | `hardware/kicad_v2/`, `docs/BOM_V2.csv` | draft, tagged `v2-design-draft` — needs hand tidy-up before fabrication (§4) |
| — | Interactive project manager / atlas / independent verification | `pm/`, `docs/atlas/`, `reviews/codex/` | Codex agent (see `PROMPT_FOR_CODEX.md`, `AGENT_STATUS.md`) |

## 2. Phase A fidelity numbers (V1 as fabricated)

| Check | Result | Evidence |
|---|---|---|
| Footprint pad positions vs film flashes | 172 / 172 pads within 0.000 mil | `validate_pcb.py` |
| Gerber XOR, KiCad export vs fabrication films | F.Cu 0.87 %, B.Cu 0.23 %, masks < 1 %, silk/outline < 1 % | `docs/A0_PROVENANCE.md` tables, `docs/img/v1_xor_*.png` |
| Drill | 53 / 53 holes within 0.05 mil of the v5 pad flashes (the shipped `.drl` is v4: 35 of its 50 holes do not exist on v5) | `A0_PROVENANCE.md` |
| Connectivity | Schematic netlist == `pstxnet.dat` == board pad nets (32 nets, 37 unconnected pins) | `check_netlist.py` PASS |
| DRC | 0 errors, 0 unconnected with the as-fabricated `.kicad_dru`; 67 documented warnings (the 7.6-mil LQFP fan-out and 37 mask bridges that are on the real board) | `hardware/kicad/_build/drc.rpt` |
| ERC | 0 violations | `_build/erc.rpt` |

Three wiring questions the old notes left open were answered from copper (`docs/img/v1_evidence_*.png`): PA8/TIM1 drives the SPEEDCONTROLLER header and PC6/TIM3 the STEERINGSERVO header; CEXT sits between VCAP_1 (pin 30) and +3V3, not ground; the CAN transceiver RXD is on PA10 (no CAN alternate function), so CAN never worked.

## 3. V1 findings that drive V2 (full list with evidence in `docs/V1_DESIGN_REVIEW.md`)

- **Safety:** no link-loss failsafe (last thrust persists), both actuator headers put +3V3 on the servo/ESC power pin, the ESC arms 10 ms after reset, no fuse / reverse-polarity / TVS on the battery input, no watchdog.
- **Functional:** SF12/BW125 gives about one command per second and the RYLR998 rejects SF12 outright; CAN unusable as wired; GPS header pin 3 held low by PB0; debug prints go into the GPS RX line.
- **Reliability:** VCAP returned to +3V3, VBAT/BOOT0 floating, no crystal (HSI only), no mounting holes (the 1.4 mm holes are live test points), 40 track pairs below the design rule of 12 mil, 37 untented-via mask bridges.

## 4. V2 in one page

**Kept:** STM32F446RET6 LQFP-64, R1240N 3.3 V buck (now with its catch diode, feedback and compensation network corrected), 2-layer board, Samtec 10-pin SWD header, Reyax RYLR UART module socket, 2.54 mm GNSS header.

**Added / changed (REQ ids in `docs/V2_REQUIREMENTS.md`):** XT30 battery input with 3 A fuse, P-FET reverse protection, SMAJ33A TVS and 47 µF bulk (REQ-PWR-01..03); 20 mΩ shunt + INA180 current sense and a filtered battery divider on the ADC (REQ-PWR-06/07); TPS54202 5 V servo buck OR-ed with the ESC BEC through SS34 diodes, so the actuator headers carry 5 V, never the logic rail (REQ-CTL-02); ESC/servo signals through 74AHCT1G125 level shifters with series resistors and PESD clamps on JST XH connectors (REQ-CTL-03/04); 8 MHz HSE and 32.768 kHz LSE crystals, NRST RC, VBAT/BOOT0 terminated (REQ-MCU-01..04); four status LEDs (REQ-DBG-02); USB-C CDC console with USBLC6 protection (REQ-DBG-01); ICM-20948 IMU on I2C with interrupt, GNSS PPS on PB0 (REQ-NAV-01..03); LoRa supply filter returned to ground, module reset driven by PA3 (REQ-RF-02/03); CAN dropped (frees PA11/PA12 for USB); four M3 mounting holes on a 72 × 38 mm pattern (REQ-MECH-01); seven test points.

**Numbers:** 118 parts, 71 nets, 68 BOM lines, board-only parts cost **$53.80 at qty 1** (`docs/BOM_V2.csv`, catalogue estimates dated 2026-09-16; the LoRa and GNSS modules, PCB and assembly are extra). Board 80 × 46 mm, 2 layers, Default class 0.25 mm track / 0.15 mm clearance, Power class 0.6 mm / 0.2 mm, vias 0.6/0.3 and 0.8/0.4 mm. Routing (freerouting 2.1.0 through `route_v2.py`, B.Cu pour as the routing plane): 1075 track segments, 165 vias, kicad-cli DRC **0 violations**; **2 GND connections still open** (two small pour islands near the LQFP fan-out at (42, 18.5) mm and near the USB block at (55.7, 9.2) mm that the automatic stitcher could not reach with a straight or L-shaped track; hand-finish with one via each in KiCad, or leave to the next layout); 101 silkscreen warnings (reference text over pads) left for the hand tidy-up. ERC 0 errors, 1 accepted warning (U6 SDO/AD0 tied to GND).
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

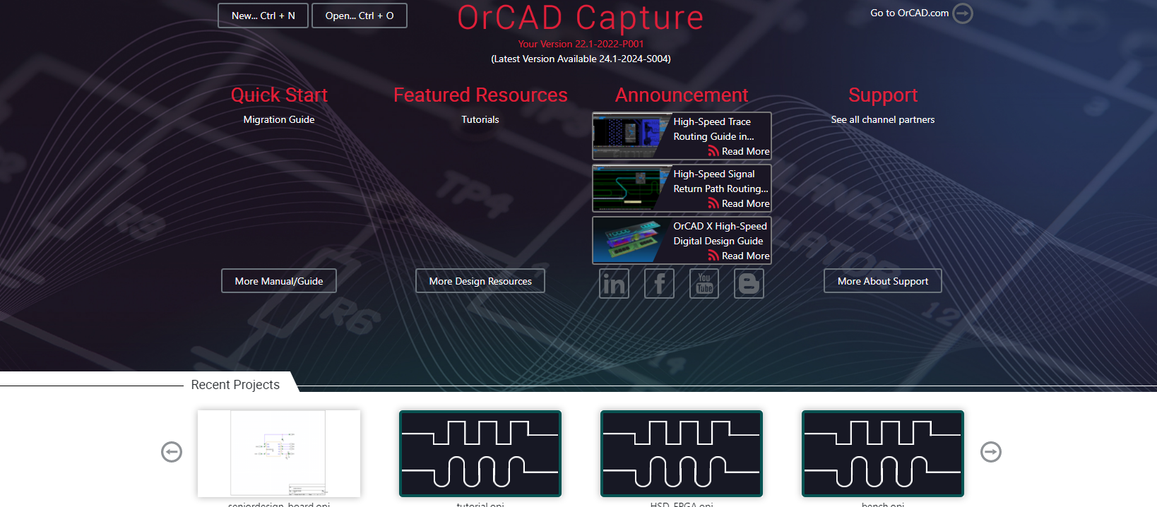
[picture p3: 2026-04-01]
Allegro/hardware/allegro-original/Allegro v5/SENIORDESIGN_BOARD.png

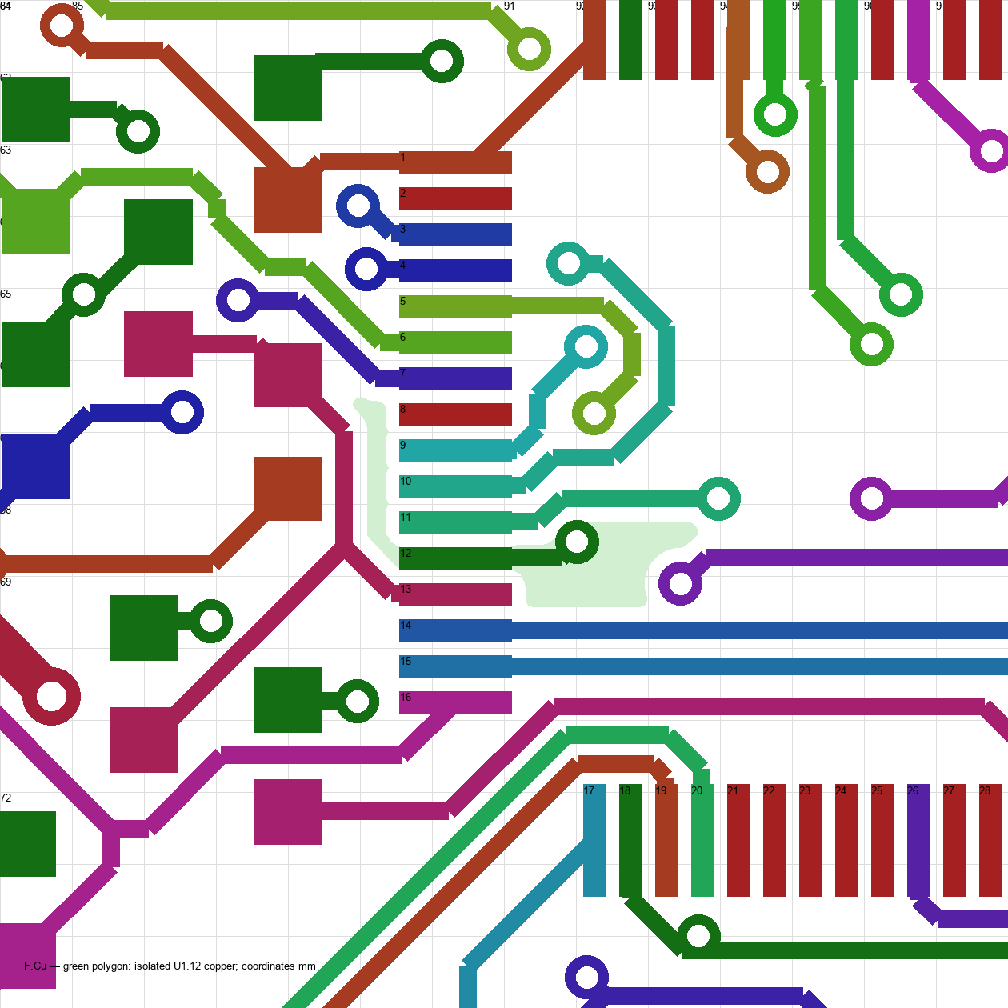
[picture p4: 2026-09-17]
reviews/codex/design_completion/mcu_ground/local_0.png

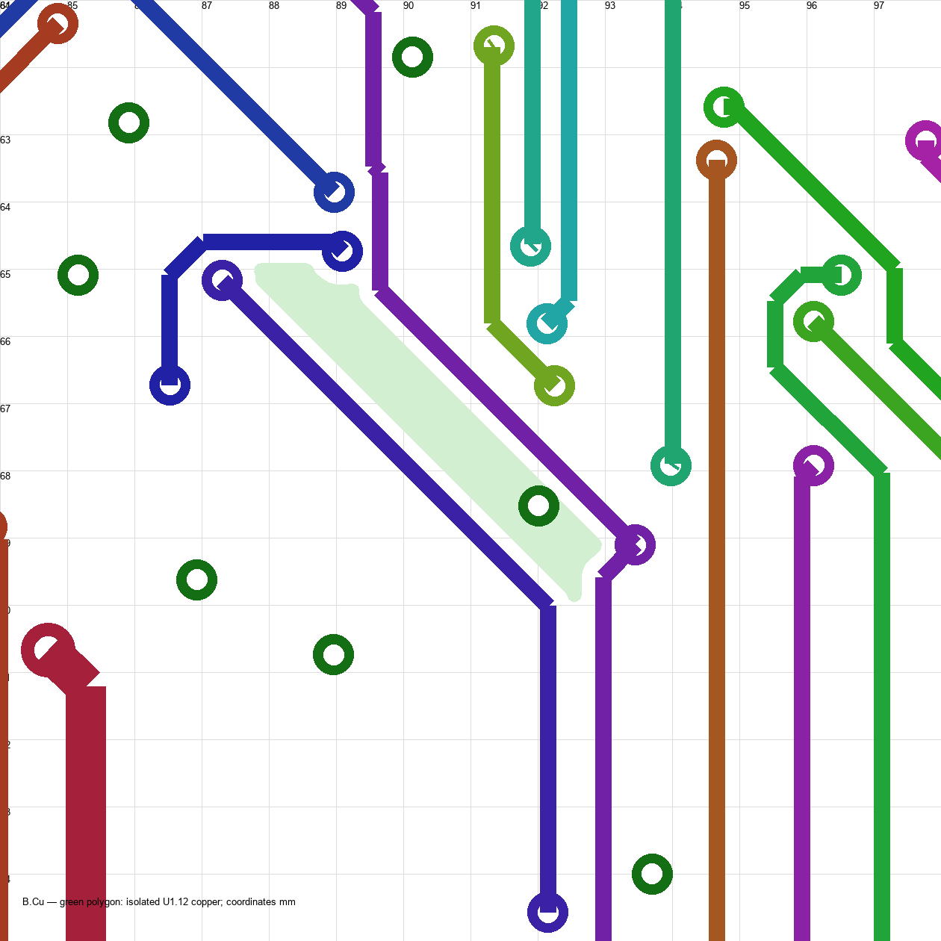
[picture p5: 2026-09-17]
reviews/codex/design_completion/mcu_ground/local_1.png

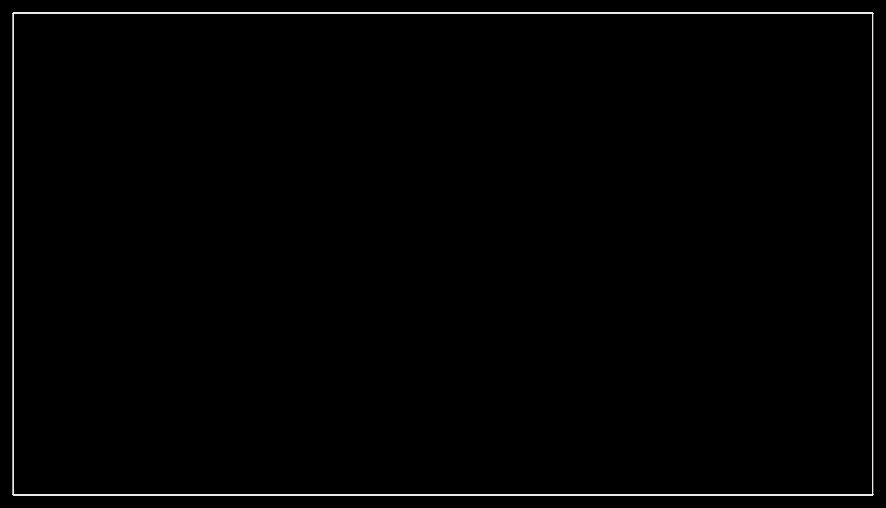
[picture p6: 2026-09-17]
docs/img/v1_xor_Edge_Cuts.png

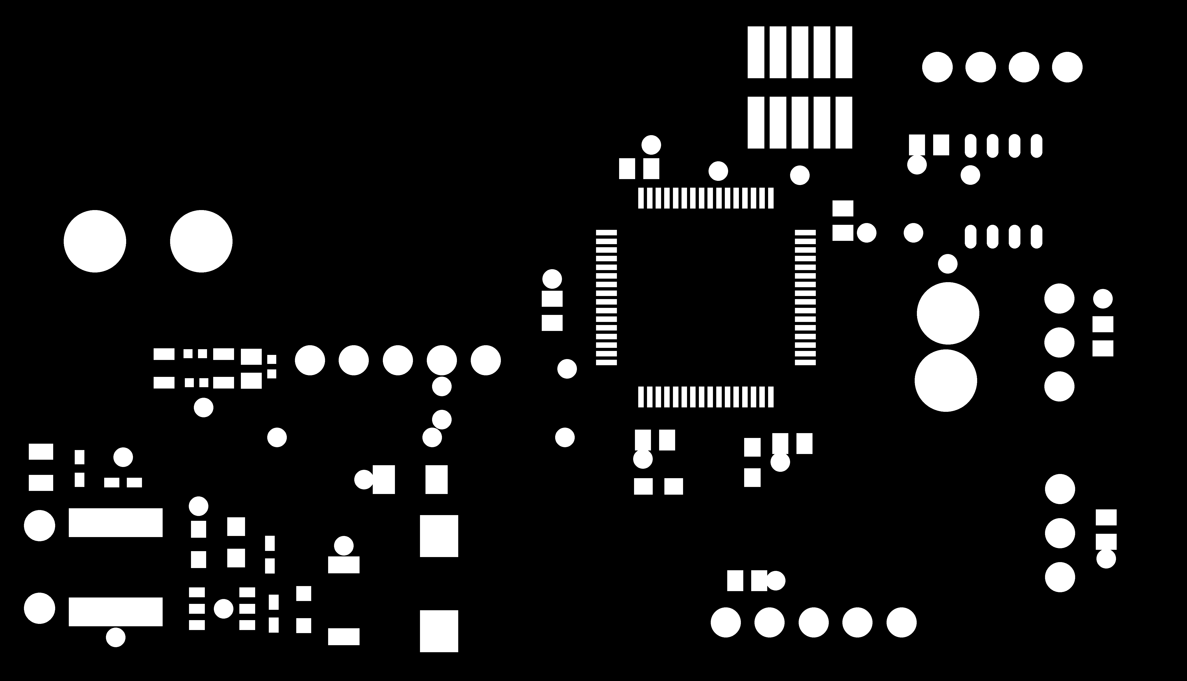
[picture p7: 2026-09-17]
docs/img/v1_kicad_F_Mask.png

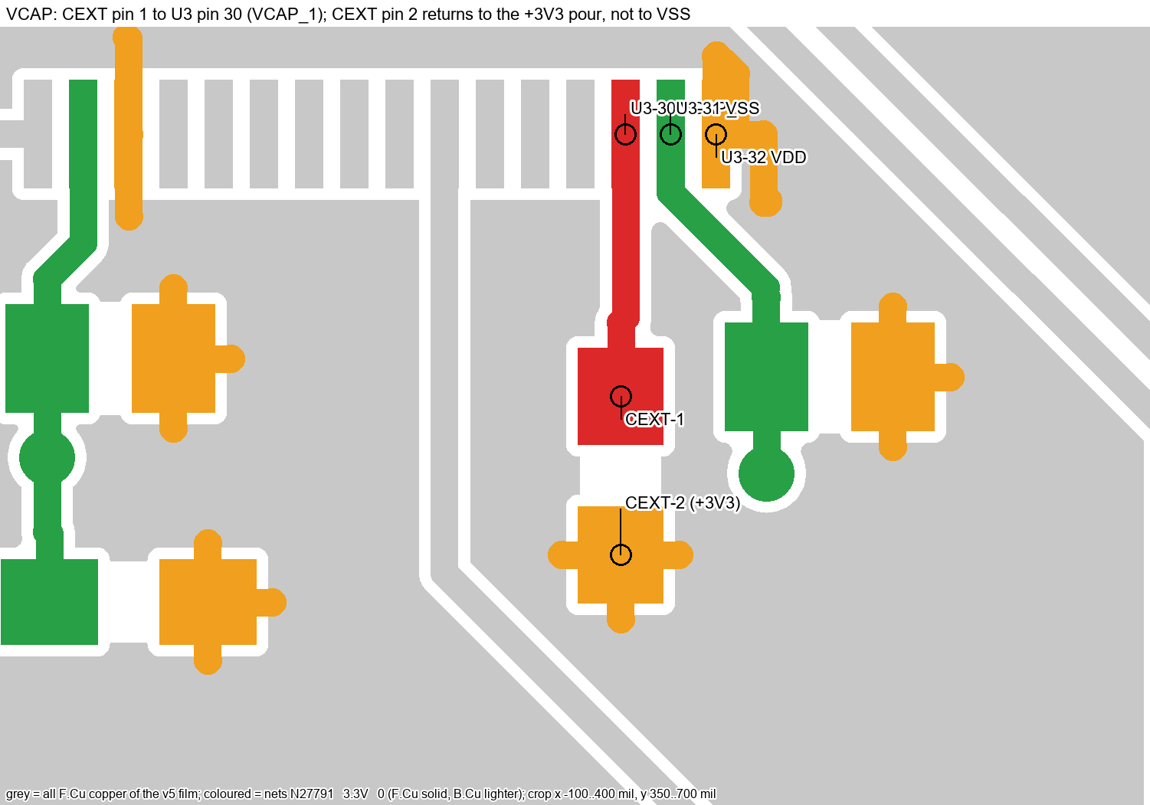
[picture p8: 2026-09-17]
docs/img/v1_evidence_vcap.png

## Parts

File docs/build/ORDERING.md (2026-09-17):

# Parts and board ordering

Use **V1 for the existing boat's inspection and repair**. Use **V2 as the developing vehicle-node design**. Neither package is a new-board manufacturing release. V1 retains known electrical defects from the original hardware; V2 still needs final electrical, layout, firmware and assembly validation. The handheld's voice, text, location, display and controls need a separate hardware BOM.

## Pick the right files

| Task | V1 existing board | V2 vehicle-node draft |
|---|---|---|
| Review every PCB item | [BOM review](../../hardware/manufacturing/v1/bom_review.csv) | [BOM review](../../hardware/manufacturing/v2/bom_review.csv) |
| Resolve parts held out of ordering | [Held parts](../../hardware/manufacturing/v1/holds.csv) | [Held parts](../../hardware/manufacturing/v2/holds.csv) |
| Get a quote for candidate parts, one board | [One-board CSV](../../hardware/manufacturing/v1/distributor_candidates_1board.csv) | [One-board CSV](../../hardware/manufacturing/v2/distributor_candidates_1board.csv) |
| Get a quote for candidate parts, five boards | [Fleet-five CSV](../../hardware/manufacturing/v1/distributor_candidates_fleet5.csv) | [Fleet-five CSV](../../hardware/manufacturing/v2/distributor_candidates_fleet5.csv) |
| Quote another selected board count | [Selected-count CSV](../../hardware/manufacturing/v1/distributor_candidates_selected.csv) | [Selected-count CSV](../../hardware/manufacturing/v2/distributor_candidates_selected.csv) |
| Complete the system beyond the PCB | [External parts decisions](../../hardware/manufacturing/v1/external_parts_review.csv) | [External parts decisions](../../hardware/manufacturing/v2/external_parts_review.csv) |
| Assemble or inspect | [V1 assembly guide](ASSEMBLY_V1.md) | [V2 assembly guide](ASSEMBLY_V2.md) |

**Candidate-order CSVs are partial lists.** They omit held selections, optional populations awaiting a decision, and bare PCB features. `CANDIDATE` means the source has a manufacturer and MPN and no specific hold in this review. It does not mean the part was checked against today's catalogue, approved for the footprint, or purchased. Full quantities and omissions are visible in the BOM review and [run manifest](../../hardware/manufacturing/run_manifest.json).

The current packet reconciles 44 V1 footprints (20 candidate components, 18 held components, 6 bare features) and 118 V2 footprints (74 candidate components, 33 held components, 11 bare features). The V2 BOM's `TOTAL` row is excluded. These counts are by reference, not by distinct part number. The [electrical review](../../reviews/codex/design_completion/electrical/README.md) adds holds for every reference affected by its six circuit findings. Fresh generated counts are in each `summary.json` and the manifest; the earlier 90/17/11 split describes the previous edition.

## Import a candidate list

1. Choose the board version and quantity. Read its held-parts file before treating the import as a complete shopping list.
2. Upload the CSV to a distributor's list/quote tool. Map `Manufacturer Part Number` to the manufacturer part field, `Quantity` to quantity, and `Customer Reference` to your reference field. Preserve punctuation in part numbers such as `CMS06(TE12L,Q,M)` and `PESD5V0S1BA,115`; the CSV quotes these correctly.
3. Review every matched manufacturer, ordering suffix, package, temperature grade and packaging unit. Resolve alternatives against the electrical requirement and footprint before selecting them. A search suggestion is not an approved substitute.
4. Record the supplier SKU, current stock, unit price, MOQ/reel constraints, chosen quantity and quote date in a saved supplier quote. Confirm the actual supplied count, especially for strips/reels. No current price or availability is promised by this packet.
5. Add the approved held/optional parts and external hardware to the quote. Keep the final accepted quote with the release record before checkout.

Mouser's [Price and Availability Assistant](https://www.mouser.com/en/price-availability/) accepts CSVs with manufacturer part numbers and quantities. DigiKey provides [My Lists](https://www.digikey.com/en/mylists), with [Customer Reference column mapping](https://www.digikey.com/en/blog/q-a-from-digi-keys-list-management-webinar). These tools were checked on 2026-09-17; no account, cart or order was created.

## Quantities and population decisions

The exporter always provides one-board and five-board quantities. Select another quantity with:

```powershell
& 'C:/Users/Jay/AppData/Local/Programs/KiCad/9.0/bin/python.exe' hardware/manufacturing/prepare_release.py --boards 3
```

`selected` means the latest `--boards` value in the manifest. Fleet-five always means five identical boards of that version. It does not include a handheld, spare boards, attrition, reusable tools, vehicles or shipping. No spare percentage is added silently.

V2 has two source-described population options: the on-board 5 V converter and the LSE clock. Their reference groups are recorded in [procurement policy](../../hardware/manufacturing/procurement_policy.json). An omitted optional group must be reviewed as a circuit, including its effect on firmware and power sources. The generated source BOM currently counts all components; the ordering helper holds these choices instead of inventing a DNP decision.

V1 holds include the C23 value/MPN conflict, tentative passives/ferrites and source lifecycle concerns. V2 holds include ordering-suffix confirmation, connector mechanical checks and population decisions. None has been silently substituted.

## Bare PCB and assembled-board quotes

There is no fabrication-order ZIP in this packet. Use the review package to prepare a quote conversation, then export manufacturing files only from a frozen, reviewed CAD revision.

Before a board order, record the approved board revision, stack-up/material, thickness, copper weights, finish, solder mask, electrical test, outline and drill source, fabrication tolerances and quantity. Do not infer a stack-up or drill certification from a board render. V1's drill reconstruction is inferred from v5 pad evidence; it is not a recovered original v5 drill file.

For assembled boards, additionally freeze the population/DNP list, exact orderable MPNs, supplier substitutions, stencil/paste requirements and assembler-specific centroid rotation/origin convention. The supplied `positions_review.csv` uses raw KiCad rotations and top-view coordinates; it is **not a production pick-and-place file**. Have the assembler confirm orientation against the annotated pad maps and exact package drawings.

The [procurement handoff](PROCUREMENT_HANDOFF.md) lists the concrete release checks and the reproducible commands. No purchase, quote submission or fabrication order has been placed.

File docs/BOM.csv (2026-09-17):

Ref | Allegro_RefDes | Qty | Value | MPN | Manufacturer | Description | Footprint | Confidence | Unit price qty1 USD | Price source (2026-09-16)
C1 | C1 | 1 | 0.1uF | KGM21NR71H104KT | Kyocera AVX | 0.1 uF 10% 50 V X7R MLCC 0805 | LoRa_Boat_Controller:CAP_KGM21_KAV-L | HIGH | 0.11 | Mouser
C10 | C10 | 1 | 4.7uF | CL10A475KP8NNNC | Samsung Electro-Mechanics | 4.7 uF 10% 10 V X5R MLCC 0603 (design gives CL10A + 0603 only; 10 V chosen) | LoRa_Boat_Controller:CAP_0603_CL10A_1P6XP8_SAM-M | MEDIUM | 0.11 | Mouser
C12 | C12 | 1 | 0.1uF | CL10B104KB8NNNC | Samsung Electro-Mechanics | 0.1 uF 10% 50 V X7R MLCC 0603 (design gives CL10 + 0603 only) | LoRa_Boat_Controller:CAP_CL10_SAM-M | MEDIUM | 0.16 | Mouser
C14 | C14 | 1 | 470pF | 06035A471JAT2A | Kyocera AVX | 470 pF 5% 50 V C0G MLCC 0603 (global PN KGM15ACG1H471JT) | LoRa_Boat_Controller:CAP_0603G_AVX-M | MEDIUM | 0.12 | Mouser
C2 | C2 | 1 | 0.1uF | KGM21NR71H104KT | Kyocera AVX | 0.1 uF 10% 50 V X7R MLCC 0805 | LoRa_Boat_Controller:CAP_KGM21_KAV-L | HIGH | 0.11 | Mouser
C20 | C20 | 1 | 10uF | GRM21BR61C106KE15L | Murata | 10 uF 10% 16 V X5R MLCC 0805 (design gives GRM21 only) | LoRa_Boat_Controller:G-21_MUR-L | MEDIUM | 0.12 | Mouser
C21 | C21 | 1 | 10uF | GRM21BR61C106KE15L | Murata | 10 uF 10% 16 V X5R MLCC 0805 (design gives GRM21 only) | LoRa_Boat_Controller:G-21_MUR-L | MEDIUM | 0.12 | Mouser
C22 | C22 | 1 | 0.1uF | KGM21NR71H104KT | Kyocera AVX | 0.1 uF 10% 50 V X7R MLCC 0805 | LoRa_Boat_Controller:CAP_KGM21_KAV-L | HIGH | 0.11 | Mouser
C23 | C23 | 1 | 47pF | GJM1555C1H220JB01D | Murata | 22 pF 5% 50 V C0G MLCC 0402 - NOTE: device name encodes 22 pF, schematic value says 47 pF (GJM1555C1H470JB01D); resolve | LoRa_Boat_Controller:CAP_GJM1555C1H220JB01__MUR-L | HIGH (MPN) / value conflict | 0.15 | Mouser
C3 | C3 | 1 | 0.1uF | KGM21NR71H104KT | Kyocera AVX | 0.1 uF 10% 50 V X7R MLCC 0805 | LoRa_Boat_Controller:CAP_KGM21_KAV-L | HIGH | 0.11 | Mouser
C4 | C4 | 1 | 0.1uF | KGM21NR71H104KT | Kyocera AVX | 0.1 uF 10% 50 V X7R MLCC 0805 | LoRa_Boat_Controller:CAP_KGM21_KAV-L | HIGH | 0.11 | Mouser
C5 | C5 | 1 | 0.1uF | KGM21NR71H104KT | Kyocera AVX | 0.1 uF 10% 50 V X7R MLCC 0805 | LoRa_Boat_Controller:CAP_KGM21_KAV-L | HIGH | 0.11 | Mouser
C6 | C6 | 1 | 0.1uF | KGM21NR71H104KT | Kyocera AVX | 0.1 uF 10% 50 V X7R MLCC 0805 | LoRa_Boat_Controller:CAP_KGM21_KAV-L | HIGH | 0.11 | Mouser
C7 | C7 | 1 | 0.1uF | KGM21NR71H104KT | Kyocera AVX | 0.1 uF 10% 50 V X7R MLCC 0805 | LoRa_Boat_Controller:CAP_KGM21_KAV-L | HIGH | 0.11 | Mouser
C8 | C8 | 1 | 0.1uF | KGM21NR71H104KT | Kyocera AVX | 0.1 uF 10% 50 V X7R MLCC 0805 | LoRa_Boat_Controller:CAP_KGM21_KAV-L | HIGH | 0.11 | Mouser
C9 | C9 | 1 | 0.1uF | KGM21NR71H104KT | Kyocera AVX | 0.1 uF 10% 50 V X7R MLCC 0805 | LoRa_Boat_Controller:CAP_KGM21_KAV-L | HIGH | 0.11 | Mouser
CANHEADER1 | CANHEADER | 1 | B4B-XH-A | B4B-XH-A(LF)(SN) | JST | XH 2.5 mm 4-position vertical through-hole header | LoRa_Boat_Controller:CONN_B4B-XH-A_JST | HIGH | 0.21 | Digi-Key
CEXT1 | CEXT | 1 | 4.7uF | CL10A475KP8NNNC | Samsung Electro-Mechanics | 4.7 uF 10% 10 V X5R MLCC 0603 (design gives CL10A + 0603 only; 10 V chosen) | LoRa_Boat_Controller:CAP_0603_CL10A_1P6XP8_SAM-M | MEDIUM | 0.11 | Mouser
CIN1 | CIN | 1 | 10uF | KTS500B106M55N0T00 | Nippon Chemi-Con | 10 uF 20% 50 V X7R MLCC 2220 (NTS series; not Kemet, not 1210) | LoRa_Boat_Controller:CAP_NTS_55_2P8T_NIP | HIGH | 4.37 | Mouser
COUT1 | COUT | 1 | 10uF | GRM31CR71E106KA12L | Murata | 10 uF 10% 25 V X7R MLCC 1206 (design gives GRM31 only) | LoRa_Boat_Controller:G-31_MUR-M | MEDIUM | 0.33 | Mouser
D21 | D21 | 1 | CMS06(TE12L,Q,M) | CMS06(TE12L,Q,M) | Toshiba | Schottky barrier diode 30 V 2 A, M-FLAT (buck catch diode) | LoRa_Boat_Controller:M-FLAT_TOS-L | HIGH | 0.88 | Mouser
GND1 | GND | 1 | Battery- |  |  | Bare battery wire solder pad 1.6 mm / 0.6 mm hole (no part) | LoRa_Boat_Controller:amv_con1 | n/a |  | -
GPSMODULE1 | GPSMODULE | 1 | PPTC051LFBN-RC | PPTC051LFBN-RC | Sullins Connector Solutions | 1x5 2.54 mm female header, through-hole | LoRa_Boat_Controller:CONN5_1LFBN-RC_SUL | HIGH | 0.38 | Digi-Key
JTAG1 | JTAG | 1 | FTSH-105-XX-X-DV | FTSH-105-01-L-DV-K | Samtec | 2x5 1.27 mm SMT header, keyed (ARM Cortex 10-pin debug) | LoRa_Boat_Controller:SAMTEC_FTSH-105-XX-X-DV | HIGH | 1.24 | Mouser
L1 | L1 | 1 | 4.7uH | SLF7045T-4R7M2R0-PF | TDK | 4.7 uH 20% 2.0 A shielded power inductor 7x7x4.5 mm - EOL (TDK PCN 2024-07-30, last ship 2026-12-31); substitute VLS6045EX-4R7M-H needs a new footprint | LoRa_Boat_Controller:IND_7045_TDK | HIGH (obsolete) | 0.37 | Arrow residual stock
L3 | L3 | 1 | BLM15 ferrite | BLM15AG601SN1D | Murata | Ferrite bead 600 ohm @100 MHz 300 mA 0402 - value not specified in the design (typical pick) | LoRa_Boat_Controller:IND_BLM15_0402_MUR-L | TBD | 0.10 | Mouser
L4 | L4 | 1 | BLM15 ferrite | BLM15AG601SN1D | Murata | Ferrite bead 600 ohm @100 MHz 300 mA 0402 - value not specified in the design (typical pick) | LoRa_Boat_Controller:IND_BLM15_0402_MUR-L | TBD | 0.10 | Mouser
LORAMODULE1 | LORAMODULE | 1 | PPTC051LFBN-RC | PPTC051LFBN-RC | Sullins Connector Solutions | 1x5 2.54 mm female header, through-hole | LoRa_Boat_Controller:CONN5_1LFBN-RC_SUL | HIGH | 0.38 | Digi-Key
R1 | R1 | 1 | 15k | ERJ-2RKF1502X | Panasonic | 15 kohm 1% 0.1 W thick film 0402 | LoRa_Boat_Controller:RC0402N_PAN-M | MEDIUM | 0.11 | Mouser
R2 | R2 | 1 | 4.7k | RC0603FR-074K7L | Yageo | 4.7 kohm 1% 0.1 W thick film 0603 | LoRa_Boat_Controller:RC0603N_YAG-M | MEDIUM | 0.10 | Mouser
R3 | R3 | 1 | 51 | RC0402FR-0751RL | Yageo | 51 ohm 1% 1/16 W thick film 0402 | LoRa_Boat_Controller:RC0402N_YAG-M | MEDIUM | 0.11 | Mouser
R4 | R4 | 1 | 5.1k | ERJ-2RKF5101X | Panasonic | 5.1 kohm 1% 0.1 W thick film 0402 | LoRa_Boat_Controller:RC0402N_PAN-M | MEDIUM | 0.10 | Mouser
R5 | R5 | 1 | 30k | RC0805FR-0730KL | Yageo | 30 kohm 1% 0805 thick film (design intent ROHM MCR10EZPF3002, no longer orderable) | LoRa_Boat_Controller:RES_R0805_ROM-M | MEDIUM (substitute) | 0.10 | estimate
R6 | R6 | 1 | 10k | RC1005F103CS | Samsung Electro-Mechanics | 10 kohm 1% 1/16 W thick film 0402 | LoRa_Boat_Controller:RES_1005_SAM-M | MEDIUM | 0.10 | Digi-Key
SPEEDCONTROLLER1 | SPEEDCONTROLLER | 1 | PPTC031LFBN-RC | PPTC031LFBN-RC | Sullins Connector Solutions | 1x3 2.54 mm female header, through-hole | LoRa_Boat_Controller:CONN_PPTC031_SUL | HIGH | 0.30 | Digi-Key
STEERINGSERVO1 | STEERINGSERVO | 1 | PPTC031LFBN-RC | PPTC031LFBN-RC | Sullins Connector Solutions | 1x3 2.54 mm female header, through-hole | LoRa_Boat_Controller:CONN_PPTC031_SUL | HIGH | 0.30 | Digi-Key
TP1 | TP1 | 1 | TP |  |  | Bare plated test-point pad 3.4 mm / 1.4 mm hole (no part; Keystone 5020 would need a footprint change) | LoRa_Boat_Controller:amv_test_point | TBD |  | -
TP3 | TP3 | 1 | TP |  |  | Bare plated test-point pad 3.4 mm / 1.4 mm hole (no part; Keystone 5020 would need a footprint change) | LoRa_Boat_Controller:amv_test_point | TBD |  | -
TP4 | TP4 | 1 | TP |  |  | Bare plated test-point pad 3.4 mm / 1.4 mm hole (no part; Keystone 5020 would need a footprint change) | LoRa_Boat_Controller:amv_test_point | TBD |  | -
TP5 | TP5 | 1 | TP |  |  | Bare plated test-point pad 3.4 mm / 1.4 mm hole (no part; Keystone 5020 would need a footprint change) | LoRa_Boat_Controller:amv_test_point | TBD |  | -
U3 | U3 | 1 | STM32F446RET6 | STM32F446RET6 | STMicroelectronics | Arm Cortex-M4 180 MHz, 512 KB flash, 128 KB SRAM, LQFP-64 (TR = tape-and-reel of the same die) | LoRa_Boat_Controller:LQFP64-10x10mm | HIGH | 10.57 | Mouser
U5 | U5 | 1 | TCAN1042HDRQ1 | TCAN1042HDRQ1 | Texas Instruments | Automotive CAN FD transceiver, 5 V VCC, SOIC-8 (Mouser flags EOL; TI successor TCAN1044A-Q1) | LoRa_Boat_Controller:D0008A_L | HIGH | 2.19 | Mouser
U6 | U6 | 1 | R1240N001B-TR-FE | R1240N001B-TR-FE | Nisshinbo Micro Devices (ex-Ricoh) | 1.25 MHz asynchronous step-down DC/DC, 4.5-30 V in, 1.2 A, SOT-23-6W | LoRa_Boat_Controller:SOT-23-6W_PE-SOT23-6W-0512_NMD | HIGH | 1.77 | Mouser
VIN1 | VIN | 1 | Battery+ |  |  | Bare battery wire solder pad 1.6 mm / 0.6 mm hole (no part) | LoRa_Boat_Controller:amv_con1 | n/a |  | -

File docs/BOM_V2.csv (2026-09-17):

Item | Qty | Refs | Value | MPN | Manufacturer | Description | Footprint | Sheet | Unit price qty1 USD | Ext price USD
1 | 1 | J1 | BATTERY XT30 | XT30PW-M | Amass | Battery input 7-25 V, board only (<= 3 A) | Connector_AMASS:AMASS_XT30PW-M_1x02_P2.50mm_Horizontal | Power | 1.20 | 1.20
2 | 1 | F1 | 3A | 0468003.NR | Littelfuse | 3 A fast-acting 1812 fuse on the board feed | Fuse:Fuse_1812_4532Metric | Power | 0.55 | 0.55
3 | 1 | Q1 | AO3401A | AO3401A | Alpha & Omega | P-MOSFET reverse-polarity protection (-30 V, 4 A) | Package_TO_SOT_SMD:SOT-23 | Power | 0.35 | 0.35
4 | 1 | D2 | 10V | BZT52C10-7-F | Diodes Inc | Gate-source clamp for Q1 (10 V: AO3401A Vgs max is 12 V, review A-10) | Diode_SMD:D_SOD-123 | Power | 0.15 | 0.15
5 | 5 | R1 R6 R8 R14 R15 | 100k | RC0603FR-07100KL | Yageo | Q1 gate pull-down | Resistor_SMD:R_0603_1608Metric | Power | 0.10 | 0.50
6 | 1 | D1 | SMAJ33A | SMAJ33A | Littelfuse | 33 V unidirectional TVS on VIN_RAW (pin 1 = cathode to VIN_RAW) | Diode_SMD:D_SMA | Power | 0.45 | 0.45
7 | 1 | C1 | 47uF 50V | EEE-FK1H470P | Panasonic | Bulk input capacitor | Capacitor_SMD:CP_Elec_6.3x7.7 | Power | 0.60 | 0.60
8 | 2 | C2 C10 | 10uF 50V | GRM32ER71H106KA12L | Murata | Input ceramic | Capacitor_SMD:C_1210_3225Metric | Power | 0.85 | 1.70
9 | 1 | R33 | 0.02R 1W | CRA2512-FZ-R020ELF | Bourns | Board current shunt (REQ-PWR-06) | Resistor_SMD:R_2512_6332Metric | Power | 0.55 | 0.55
10 | 1 | U8 | INA180A1 | INA180A1IDBVR | Texas Instruments | Current-sense amplifier, gain 20 (3 A = 1.2 V) | Package_TO_SOT_SMD:SOT-23-5 | Power | 0.95 | 0.95
11 | 15 | C37 C36 C7 C15 C16 C17 C18 C22 C23 C24 C31 C33 C34 C13 C14 | 100nF | KGM15ACG1H104KT | Kyocera AVX | INA180 output filter | Capacitor_SMD:C_0603_1608Metric | Power | 0.10 | 1.50
12 | 3 | R31 R27 R28 | 47k | RC0603FR-0747KL | Yageo | Battery divider top (26 V -> 3.3 V) | Resistor_SMD:R_0603_1608Metric | Power | 0.10 | 0.30
13 | 1 | R32 | 6.8k | RC0603FR-076K8L | Yageo | Battery divider bottom | Resistor_SMD:R_0603_1608Metric | Power | 0.10 | 0.10
14 | 1 | U2 | R1240N001B-TR-FE | R1240N001B-TR-FE | Nisshinbo | 1.25 MHz async buck, 1.2 A | LoRa_Boat_Controller:SOT-23-6W_PE-SOT23-6W-0512_NMD | Power | 1.45 | 1.45
15 | 3 | R2 R25 R26 | 5.1k | RC0603FR-075K1L | Yageo | CE pull-up to VIN_BUCK | Resistor_SMD:R_0603_1608Metric | Power | 0.10 | 0.30
16 | 1 | R3 | 51R | RC0603FR-0751RL | Yageo | Bootstrap series R (per DS) | Resistor_SMD:R_0603_1608Metric | Power | 0.10 | 0.10
17 | 1 | C3 | 100nF 50V | CL10B104KB8NNNC | Samsung | Bootstrap capacitor | Capacitor_SMD:C_0603_1608Metric | Power | 0.10 | 0.10
18 | 2 | L1 L2 | 4.7uH 3A | SRN6045TA-4R7M | Bourns | Replaces the EOL SLF7045 (F-BOM-01) | Inductor_SMD:L_Bourns_SRN6045TA | Power | 0.55 | 1.10
19 | 1 | D3 | CMS06 | CMS06(TE12L,Q,M) | Toshiba | Catch diode 30 V 2 A | LoRa_Boat_Controller:M-FLAT_TOS-L | Power | 0.60 | 0.60
20 | 1 | R4 | 15k | RC0603FR-0715KL | Yageo | FB top: Vout = 0.8 * (1 + 15/4.7) = 3.35 V | Resistor_SMD:R_0603_1608Metric | Power | 0.10 | 0.10
21 | 1 | R5 | 4.7k | RC0603FR-074K7L | Yageo | FB bottom | Resistor_SMD:R_0603_1608Metric | Power | 0.10 | 0.10
22 | 1 | C4 | 470pF | 06035A471JAT2A | Kyocera AVX | Feed-forward (CSPD) | Capacitor_SMD:C_0603_1608Metric | Power | 0.15 | 0.15
23 | 2 | C5 C6 | 10uF 25V | GRM31CR71E106KA12L | Murata | 3.3 V output | Capacitor_SMD:C_1206_3216Metric | Power | 0.45 | 0.90
24 | 1 | U3 | TPS54202 | TPS54202DDCR | Texas Instruments | 5 V / 2 A buck for the servo rail (populate option) | Package_TO_SOT_SMD:TSOT-23-6 | Power | 0.75 | 0.75
25 | 1 | R9 | 13.3k | RC0603FR-0713K3L | Yageo | FB bottom | Resistor_SMD:R_0603_1608Metric | Power | 0.10 | 0.10
26 | 2 | C8 C9 | 22uF 16V | GRM32ER61C226KE20L | Murata | 5 V output | Capacitor_SMD:C_1210_3225Metric | Power | 0.60 | 1.20
27 | 2 | D4 D9 | SS34 | SS34 | Vishay | OR-ing: on-board 5 V -> VSERVO | Diode_SMD:D_SMA | Power | 0.35 | 0.70
28 | 1 | C11 | 100uF 10V | EEE-FK1A101P | Panasonic | VSERVO bulk | Capacitor_SMD:CP_Elec_6.3x7.7 | Power | 0.40 | 0.40
29 | 1 | C12 | 10uF 16V | GRM21BR61C106KE15L | Murata | VSERVO ceramic | Capacitor_SMD:C_0805_2012Metric | Power | 0.25 | 0.25
30 | 1 | U1 | STM32F446RET6 | STM32F446RET6 | STMicroelectronics | Cortex-M4 180 MHz | Package_QFP:LQFP-64_10x10mm_P0.5mm | MCU | 9.80 | 9.80
31 | 4 | C19 C29 C30 C35 | 10uF 10V | GRM21BR61A106KE19L | Murata | VDD bulk | Capacitor_SMD:C_0805_2012Metric | MCU | 0.20 | 0.80
32 | 1 | C20 | 4.7uF 10V | CL10A475KP8NNNC | Samsung | VCAP_1 to VSS (REQ-MCU-01, fixes F-MCU-01) | Capacitor_SMD:C_0603_1608Metric | MCU | 0.12 | 0.12
33 | 1 | FB1 | 600R | BLM18AG601SN1D | Murata | VDDA filter | Inductor_SMD:L_0603_1608Metric | MCU | 0.12 | 0.12
34 | 1 | C21 | 1uF | CL10A105KB8NNNC | Samsung | VDDA | Capacitor_SMD:C_0603_1608Metric | MCU | 0.10 | 0.10
35 | 3 | R16 R11 R13 | 10k | RC0603FR-0710KL | Yageo | BOOT0 pull-down (REQ-MCU-02) | Resistor_SMD:R_0603_1608Metric | MCU | 0.10 | 0.30
36 | 1 | SW1 | RESET | KMR221GLFS | C&K | Reset button | Button_Switch_SMD:SW_Push_1P1T_NO_CK_KMR2 | MCU | 0.65 | 0.65
37 | 1 | Y1 | 8MHz | ABM8-8.000MHZ-10-1-U-T | Abracon | HSE, CL 10 pF (REQ-MCU-03) | Crystal:Crystal_SMD_3225-4Pin_3.2x2.5mm | MCU | 0.95 | 0.95
38 | 2 | C25 C26 | 15pF C0G | 06035A150JAT2A | Kyocera AVX | HSE load | Capacitor_SMD:C_0603_1608Metric | MCU | 0.15 | 0.30
39 | 1 | Y2 | 32.768kHz | ABS07-32.768KHZ-7-T | Abracon | LSE, CL 7 pF (REQ-MCU-04, populate option) | Crystal:Crystal_SMD_3215-2Pin_3.2x1.5mm | MCU | 0.70 | 0.70
40 | 2 | C27 C28 | 10pF C0G | 06035A100JAT2A | Kyocera AVX | LSE load | Capacitor_SMD:C_0603_1608Metric | MCU | 0.15 | 0.30
41 | 1 | D5 | PWR green | LTST-C193KGKT-5A | Lite-On | Power LED (REQ-PWR-08) | LED_SMD:LED_0603_1608Metric | MCU | 0.30 | 0.30
42 | 1 | D6 | LINK blue | LTST-C193TBKT-5A | Lite-On | Link LED | LED_SMD:LED_0603_1608Metric | MCU | 0.30 | 0.30
43 | 1 | D7 | FIX yellow | LTST-C193KSKT-5A | Lite-On | GNSS fix LED | LED_SMD:LED_0603_1608Metric | MCU | 0.30 | 0.30
44 | 1 | D8 | FAULT red | LTST-C193KRKT-5A | Lite-On | Fault / failsafe LED | LED_SMD:LED_0603_1608Metric | MCU | 0.30 | 0.30
45 | 4 | R29 R30 R34 R35 | 1k | RC0603FR-071KL | Yageo | LED | Resistor_SMD:R_0603_1608Metric | MCU | 0.10 | 0.40
46 | 1 | J4 | LoRa RYLR998 | PPTC051LFBN-RC | Sullins | 1x5 socket: VDD, NRST, RXD, TXD, GND (RYLR998 pinout) | LoRa_Boat_Controller:CONN5_1LFBN-RC_SUL | Radio | 0.60 | 0.60
47 | 2 | FB2 FB3 | 600R | BLM15AG601SN1D | Murata | LoRa supply pi filter | Inductor_SMD:L_0402_1005Metric | Radio | 0.12 | 0.24
48 | 1 | C32 | 47pF | GJM1555C1H470JB01D | Murata | LORA_VCC (RYLR998 reference design) | Capacitor_SMD:C_0402_1005Metric | Radio | 0.12 | 0.12
49 | 8 | R17 R18 R19 R20 R21 R22 R10 R12 | 100R | RC0603FR-07100RL | Yageo | UART4_TX series | Resistor_SMD:R_0603_1608Metric | Radio | 0.10 | 0.80
50 | 1 | J5 | GNSS | PPTC061LFBN-RC | Sullins | 1x6: VCC, GND, TX, RX, PPS, VBCKP | Connector_PinHeader_2.54mm:PinHeader_1x06_P2.54mm_Vertical | Navigation | 0.65 | 0.65
51 | 1 | U6 | ICM-20948 | ICM-20948 | TDK InvenSense | 9-axis IMU, I2C | LoRa_Boat_Controller_V2:QFN-24_3x3mm_P0.4mm_NoEP | Navigation | 11.50 | 11.50
52 | 2 | R23 R24 | 2.2k | RC0603FR-072K2L | Yageo | I2C SCL pull-up | Resistor_SMD:R_0603_1608Metric | Navigation | 0.10 | 0.20
53 | 1 | J2 | ESC | B3B-XH-A(LF)(SN) | JST | 1: signal 5 V, 2: BEC in, 3: GND | Connector_JST:JST_XH_B3B-XH-A_1x03_P2.50mm_Vertical | Actuators | 0.25 | 0.25
54 | 1 | J3 | SERVO | B3B-XH-A(LF)(SN) | JST | 1: signal 5 V, 2: VSERVO out, 3: GND | Connector_JST:JST_XH_B3B-XH-A_1x03_P2.50mm_Vertical | Actuators | 0.25 | 0.25
55 | 2 | U4 U5 | 74AHCT1G125 | SN74AHCT1G125DBVR | Texas Instruments | ESC PWM 3.3 -> 5 V buffer | Package_TO_SOT_SMD:SOT-23-5 | Actuators | 0.45 | 0.90
56 | 2 | D10 D11 | PESD5V0S1BA | PESD5V0S1BA,115 | Nexperia | ESC signal ESD | Diode_SMD:D_SOD-323 | Actuators | 0.25 | 0.50
57 | 1 | J6 | USB-C | USB4105-GF-A | GCT | USB 2.0 device console | Connector_USB:USB_C_Receptacle_GCT_USB4105-xx-A_16P_TopMnt_Horizontal | Debug | 1.10 | 1.10
58 | 1 | U7 | USBLC6-2SC6 | USBLC6-2SC6 | STMicroelectronics | USB ESD | Package_TO_SOT_SMD:SOT-23-6 | Debug | 0.55 | 0.55
59 | 1 | J7 | SWD | FTSH-105-01-L-DV-K | Samtec | ARM 10-pin Cortex debug | Connector_PinHeader_1.27mm:PinHeader_2x05_P1.27mm_Vertical_SMD | Debug | 3.20 | 3.20
60 | 1 | TP1 | ESC_PWM |  |  | MCU-side ESC PWM | TestPoint:TestPoint_Pad_D1.5mm | Actuators
61 | 1 | TP2 | SERVO_PWM |  |  | MCU-side servo PWM | TestPoint:TestPoint_Pad_D1.5mm | Actuators
62 | 1 | TP3 | +3V3 |  |  |  | TestPoint:TestPoint_Pad_D1.5mm | Power
63 | 1 | TP4 | VSERVO |  |  |  | TestPoint:TestPoint_Pad_D1.5mm | Power
64 | 1 | TP5 | VIN_RAW |  |  |  | TestPoint:TestPoint_Pad_D1.5mm | Power
65 | 1 | TP6 | GND |  |  |  | TestPoint:TestPoint_Pad_D1.5mm | Power
66 | 1 | TP7 | PPS |  |  |  | TestPoint:TestPoint_Pad_D1.5mm | Navigation
67 | 4 | H1 H2 H3 H4 | M3 |  |  | Mounting hole | MountingHole:MountingHole_3.2mm_M3 | Power
 | 118 | TOTAL (board only, qty 1, catalogue prices as of 2026-09-16) |  |  |  |  |  |  |  | 53.80

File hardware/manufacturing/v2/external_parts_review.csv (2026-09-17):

Item | MPN | Quantity | Decision needed
LoRa radio module |  | TBD | Confirm exact radio model, firmware and mating pinout; board BOM includes only socket
GNSS module |  | TBD | Select exact breakout/module, supply, update rate and pin mapping; board BOM includes only socket
Antenna and RF pigtail |  | TBD | Match selected radio connector, band, enclosure and regional configuration
Actuator mating housings / contacts / cables |  | TBD | Select wire gauge, contact plating, lengths and verified harness orientation
Battery / ESC / servo or ground-vehicle drives |  | TBD | Application-specific load and power plan; not included in controller board BOM
Enclosure / seals / mounting screws / standoffs |  | TBD | Mechanical stack and environmental protection not selected; mounting holes are not hardware items
Handheld and audio/display/control hardware |  | TBD | Separate future product BOM; not represented by either vehicle-node PCB
Programming cable / debug probe / test leads |  | TBD | Reusable tools; do not multiply automatically by fleet size

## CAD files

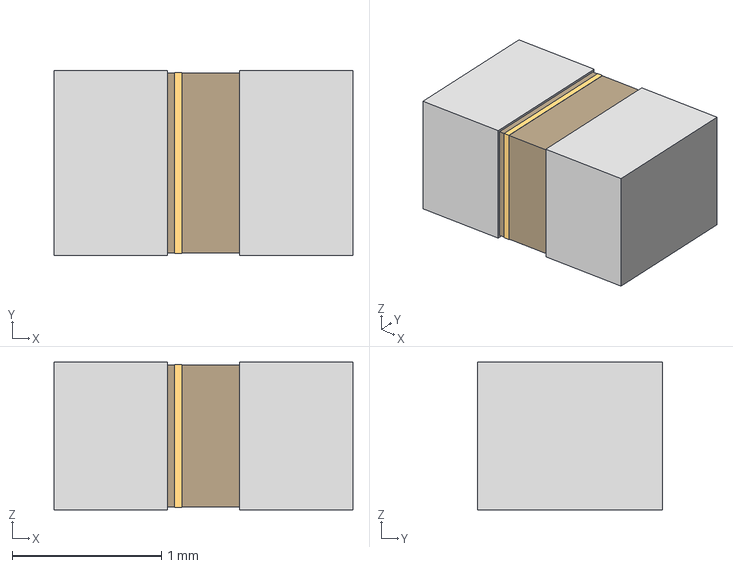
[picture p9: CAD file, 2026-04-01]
Allegro/hardware/allegro-original/Allegro v5/KGM21NR71H104KT/CAP_KGM21_KAV.step
2.01 x 1.24 x 0.991 mm

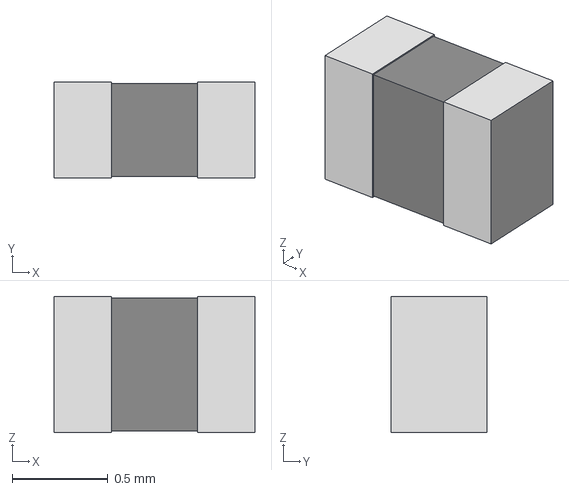
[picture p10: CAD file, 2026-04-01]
Allegro/hardware/allegro-original/Allegro v5/parts final/RC0402N_PAN.step
1.05 x 0.5 x 0.711 mm

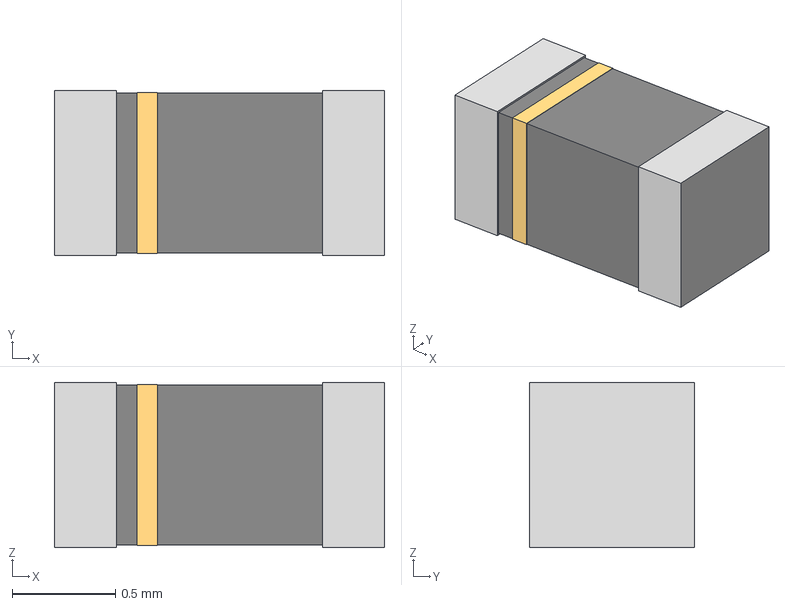
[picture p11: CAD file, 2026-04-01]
Allegro/hardware/allegro-original/Allegro v5/parts final/IND_1608_TDK.step
1.60 x 0.8 x 0.8 mm

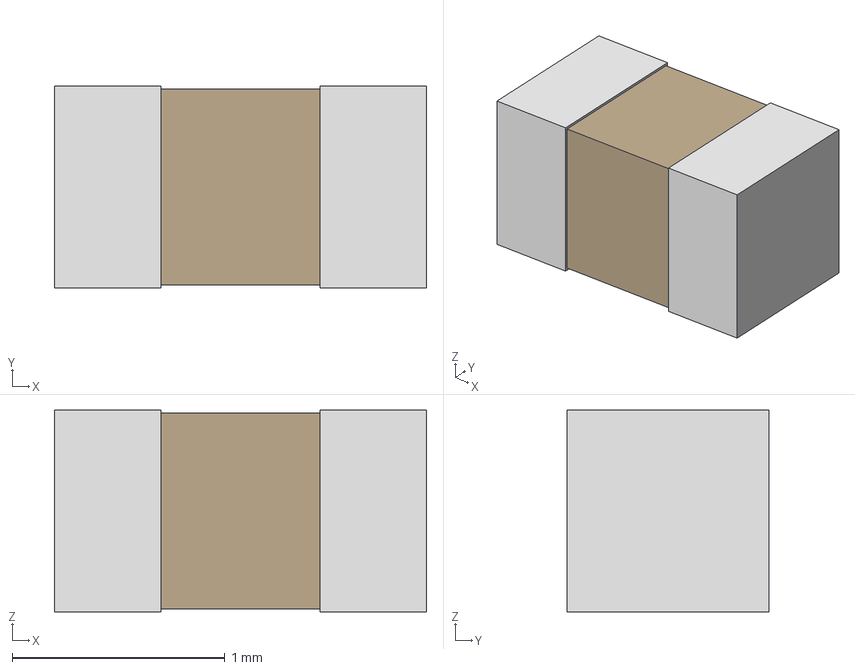
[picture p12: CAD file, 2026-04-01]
Allegro/hardware/allegro-original/Allegro v5/parts final/CAPC17595_95N_KEM.step
1.75 x 0.95 x 0.95 mm

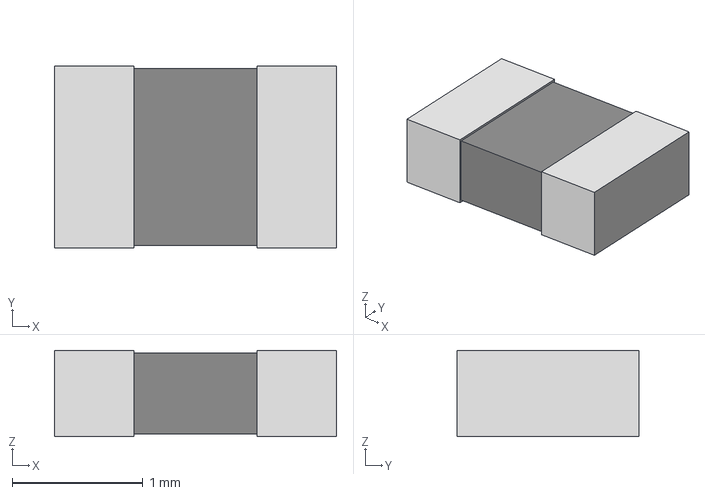
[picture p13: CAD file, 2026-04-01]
Allegro/hardware/allegro-original/Allegro v5/parts final/RES0805_CRG_TYCO_TYC.step
2.16 x 1.40 x 0.66 mm

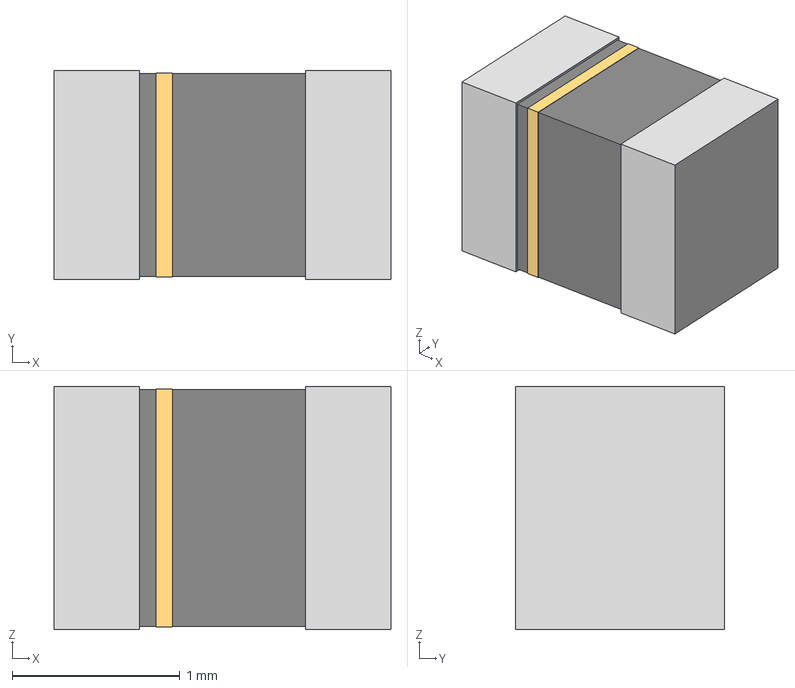
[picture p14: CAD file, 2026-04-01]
Allegro/hardware/allegro-original/Allegro v5/parts final/G-21_MUR.step
2.01 x 1.24 x 1.45 mm

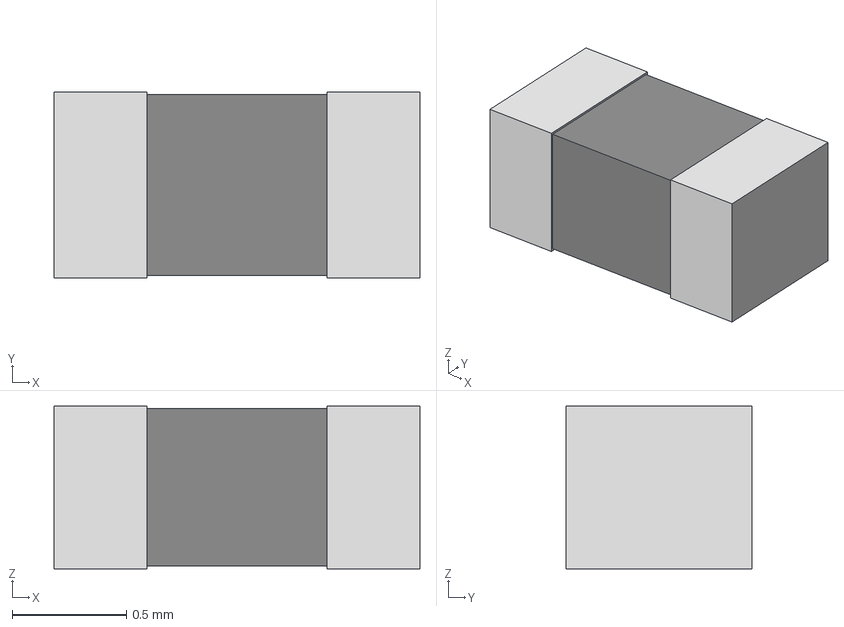
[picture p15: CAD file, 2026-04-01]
Allegro/hardware/allegro-original/Allegro v5/parts final/RC0603N_YAG.step
1.60 x 0.812 x 0.711 mm

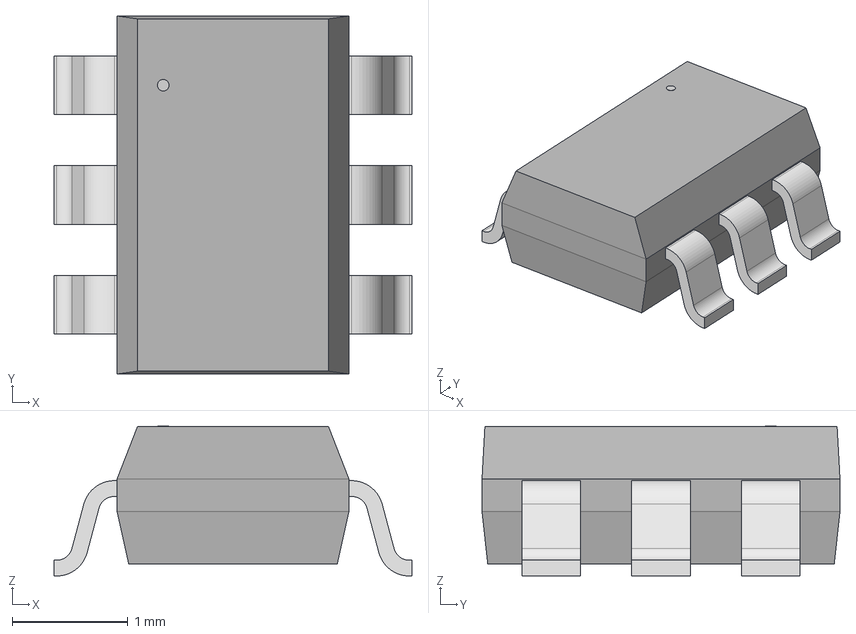
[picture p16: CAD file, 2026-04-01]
Allegro/hardware/allegro-original/Allegro v5/parts final/SOT-23-6W_PE-SOT23-6W-0512_N01.step
3.10 x 3.10 x 1.30 mm

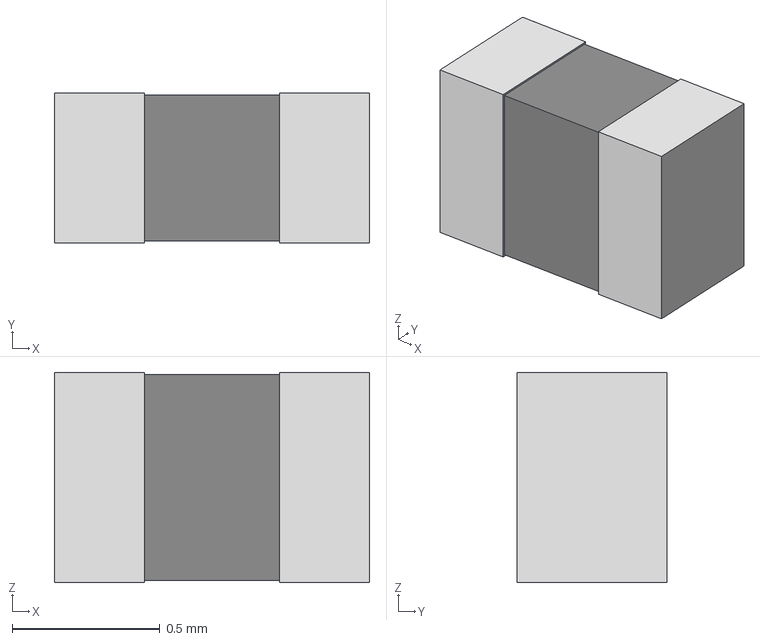
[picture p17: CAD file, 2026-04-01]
Allegro/hardware/allegro-original/Allegro v5/parts final/RC0402N_YAG.step
1.07 x 0.508 x 0.711 mm

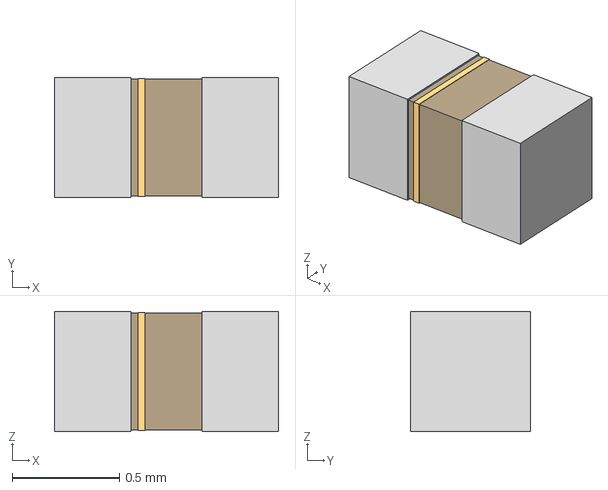
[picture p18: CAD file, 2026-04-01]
Allegro/hardware/allegro-original/Allegro v5/parts final/CAP_GJM1555C1H220JB01__MUR.step
1.04 x 0.558 x 0.559 mm

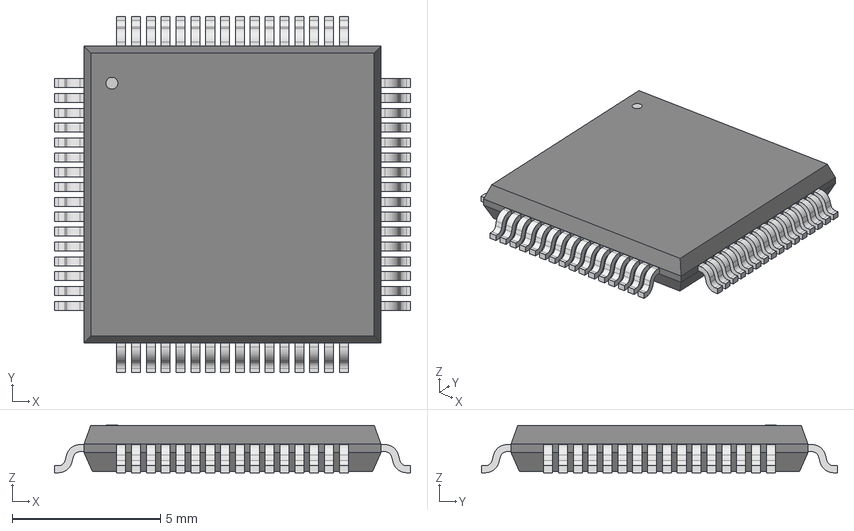
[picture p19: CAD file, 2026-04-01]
Allegro/hardware/allegro-original/Allegro v5/parts final/LQFP64-10x10mm.step
12.0 x 12.0 x 1.60 mm

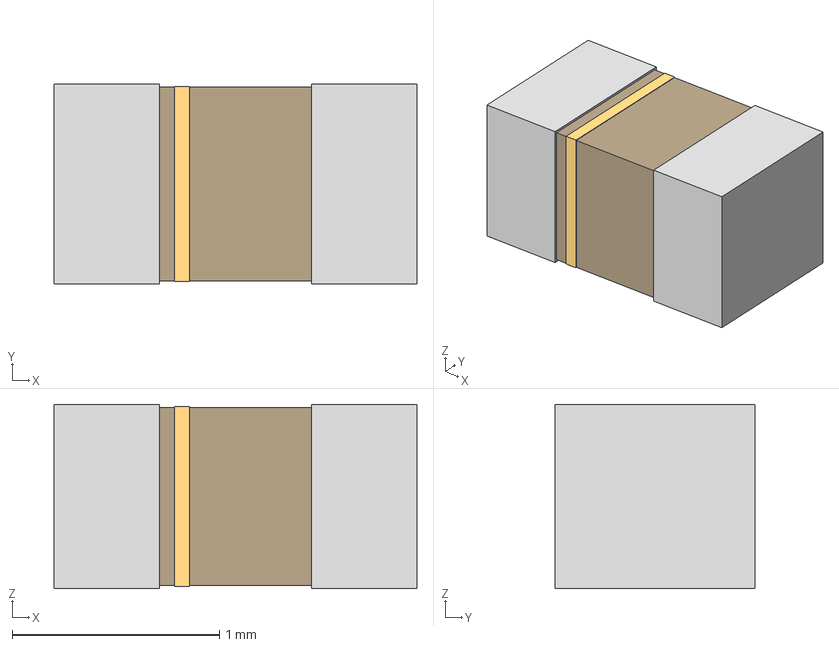
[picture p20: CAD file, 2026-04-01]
Allegro/hardware/allegro-original/Allegro v5/parts final/CAP_0603G_AVX.step
1.75 x 0.966 x 0.889 mm

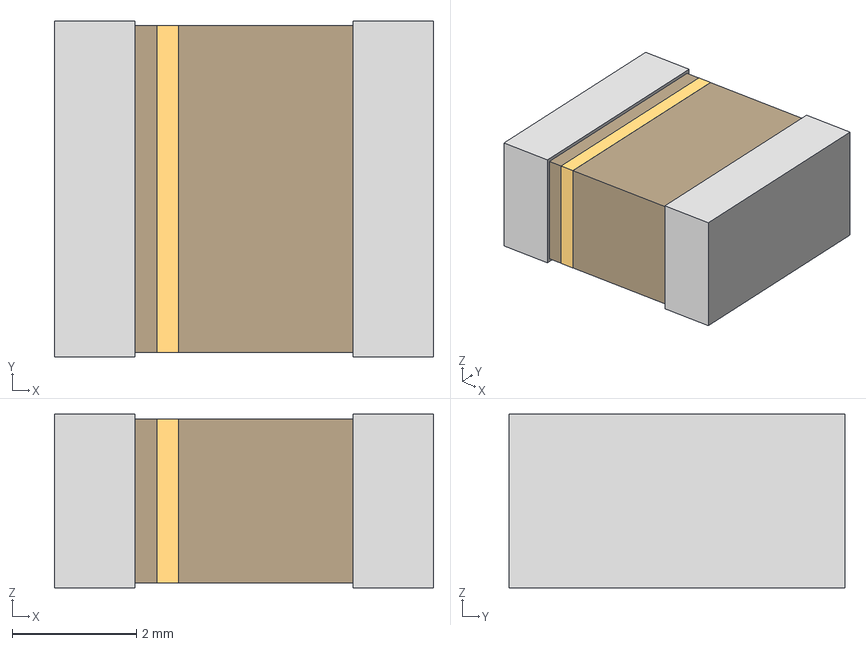
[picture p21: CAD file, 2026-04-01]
Allegro/hardware/allegro-original/Allegro v5/parts final/CAP_NTS_55_2P8T_NIP.step
6.10 x 5.41 x 2.79 mm

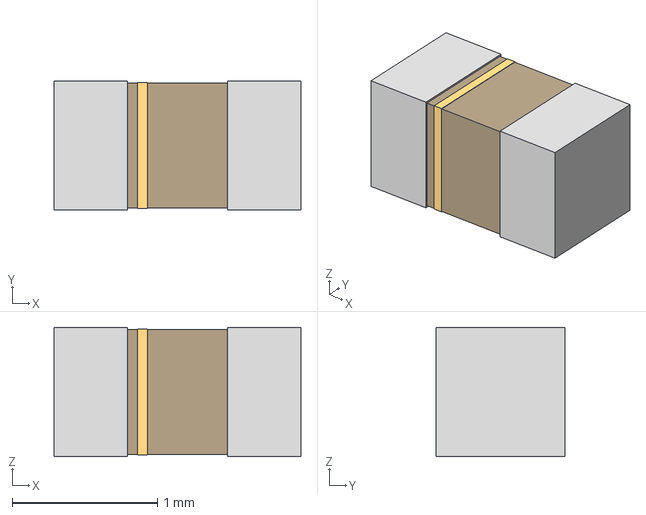
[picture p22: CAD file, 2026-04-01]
Allegro/hardware/allegro-original/Allegro v5/parts final/CAP_0603_CL10A_1P6XP8_SAM.step
1.70 x 0.888 x 0.889 mm

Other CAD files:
Allegro/hardware/allegro-original/Allegro v5/parts final/IND_BLM15_0402_MUR.step
Allegro/hardware/allegro-original/Allegro v5/parts final/SOT-23-6W_PE-SOT23-6W-0512_N00.step
Allegro/hardware/allegro-original/Allegro v5/parts final/SOT-23-6W_PE-SOT23-6W-0512_NMD.step
Allegro/hardware/allegro-original/Allegro v5/parts final/RES_LR1_TYCO_TYC.step
Allegro/hardware/allegro-original/Allegro v5/KGM21NR71H104KT/cap_kgm21_kav-l.psm
Allegro/hardware/allegro-original/Allegro v5/KGM21NR71H104KT/cap_kgm21_kav-m.psm
Allegro/hardware/allegro-original/Allegro v5/KGM21NR71H104KT/cap_kgm21_kav.psm
Allegro/hardware/allegro-original/Allegro v5/parts final/CAP_CL05_SAM.step
Allegro/hardware/allegro-original/Allegro v5/parts final/CAP_CL10_SAM.step
Allegro/hardware/allegro-original/Allegro v5/parts final/G-31_MUR.step
Allegro/hardware/allegro-original/Allegro v5/parts final/RES_1005_SAM.step
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

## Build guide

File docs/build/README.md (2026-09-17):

# Build, assemble and program

Start with the board you actually have. **V1 documents the existing boat controller; V2 is the developing multifunction vehicle node.** The future handheld must support voice, text and location alongside RC control. It does not yet have a released PCB, BOM or firmware image.

The [interactive workspace](../../pm/index.html) brings the drawings, parts, assembly maps, firmware and review evidence together. Use by application links the [application handbook](../applications/README.md); Build & program covers assembly and firmware. Keep this repository together so all linked artifacts remain available.

## Choose a build path

| Step | V1: inspect, repair and reproduce | V2: review and develop |
| --- | --- | --- |
| Read the circuit | [Annotated schematic PDF](../img/v1_schematic.pdf), [known design findings](../V1_DESIGN_REVIEW.md) | [Annotated schematic PDF](../img/v2_schematic.pdf), [requirements](../V2_REQUIREMENTS.md) |
| Select parts | [Ordering guide](ORDERING.md), [complete BOM review](../../hardware/manufacturing/v1/bom_review.csv), [held parts](../../hardware/manufacturing/v1/holds.csv) | [Ordering guide](ORDERING.md), [complete BOM review](../../hardware/manufacturing/v2/bom_review.csv), [held parts](../../hardware/manufacturing/v2/holds.csv) |
| Locate and inspect components | [Assembly procedure](ASSEMBLY_V1.md), [top map](../../hardware/manufacturing/v1/assembly_top.svg), [bottom map](../../hardware/manufacturing/v1/assembly_bottom.svg) | [Assembly procedure](ASSEMBLY_V2.md), [top map](../../hardware/manufacturing/v2/assembly_top.svg), [bottom map](../../hardware/manufacturing/v2/assembly_bottom.svg) |
| Check connector wiring | [V1 connector atlas](../atlas/README.md) and assembly guide | Assembly guide and current schematic; a complete V2 connector atlas is still needed |
| Compile | [Reproducible V1 build](FIRMWARE_BUILD.md): completed twice with identical image hashes on the recorded toolchain | [Stage A diagnostic](../../firmware_v2/README.md) builds; no operational/qualified image exists |
| Back up / program / verify | [V1 flashing procedure](FLASHING_V1.md): retain the existing image before changing hardware | [V2 bring-up and programming plan](FLASHING_V2.md): resolve the pin/protocol contract first |
| Review changes | [Review workflow](REVIEW_WORKFLOW.md), [schematic editing guide](SCHEMATICS.md) | Same checks, plus unresolved PCB routing, layout and device-level electrical review |

## From parts list to a working unit

1. Read the version's known defects and assembly prerequisites. V1 is a faithful reconstruction and retains original defects; its clean netlist comparison does not repair them.
2. Resolve the held and optional parts, then import the one-board or five-board candidate CSV from the ordering guide. These are partial quote lists, not complete approved carts. Include the external radio, GNSS, harness, power and mechanical decisions.
3. Freeze an accepted PCB/parts/population revision before requesting fabrication or assembly. The current exports are review artifacts; no Gerber, drill or pick-and-place release is approved here.
4. Inspect the unpowered board and connector polarity, then follow the assembly guide's staged power checks with actuators disconnected. Record actual measurements against board identity and input hashes.
5. Follow the version-specific firmware procedure. The V1 build is unqualified and preserves existing behavior. The V2 procedure is a development sequence, not an instruction to load the V1 binary.
6. Record backup, programming verification, reset behavior, failsafe, link loss, sensor and application tests. Passing a compiler or CAD check alone cannot complete this step.

## Review and transfer

Every change packet should contain its reason, exact changed source files, generated artifacts, input hashes, checks, remaining limitations and one next task. Read the latest [handoff](../../HANDOFF.md) and [ownership record](../../FILE_OWNERSHIP.md) before editing. Source generators and their outputs must move together in a later selective commit; no commit, upload or deployment is automatic.

The manual CI workflow runs dependency-free quality tests, optionally checks KiCad on a configured runner, and optionally compiles V1 without accessing hardware. It records evidence even when a gate fails. Local results are in the [quality handoff](../../reviews/codex/professionalization/QUALITY_HANDOFF.md), [firmware handoff](FIRMWARE_HANDOFF.md) and [procurement handoff](PROCUREMENT_HANDOFF.md).

## Next development packets

1. Resolve current V2 electrical/layout findings and all schematic-to-PCB discrepancies at a frozen revision.
2. Review the Stage A pin-checked diagnostic, finish electrical corrections and freeze the operational protocol before adding control drivers.
3. Compile and test the protocol/failsafe correction prototype, then integrate it through measured bench acceptance.
4. Complete the V2 connector atlas and exact-part datasheet coverage; approve a complete population and purchasing list.
5. Measure voice airtime, speech quality and the worst RC blocking interval before selecting handheld radio, codec or hardware. Voice, text and location remain required; no shared-radio coexistence claim is made yet.

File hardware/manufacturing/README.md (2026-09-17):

# Ordering and assembly review exports

Start with [Ordering](../../docs/build/ORDERING.md). Assembly guides: [V1 existing board](../../docs/build/ASSEMBLY_V1.md) and [V2 vehicle-node draft](../../docs/build/ASSEMBLY_V2.md). The [handoff](../../docs/build/PROCUREMENT_HANDOFF.md) describes reproduction, checks and outstanding release decisions.

`run_manifest.json` is the single generated run record. `v1/` and `v2/` contain BOM reviews, held/external-part decisions, partial distributor candidate imports, position/orientation review tables and assembly pad maps. No files here are an authorized fabrication or purchase order.

Run `prepare_release.py --boards N` using KiCad's Python to refresh outputs; run it again with `--check`, then `check_package.py`, to verify them. `procurement_policy.json` records the reviewed selection holds and population options. These tools do not modify CAD or execute primary generators.

`render_assembly.mjs` is optional local visual QA using Playwright and Edge. It renders SVGs into `previews/`; the generated SVGs are the reproducible drawing artifacts. Preview PNGs are not manufacturing files and are outside the run manifest's released-data hash list.

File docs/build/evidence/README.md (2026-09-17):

# Portable report evidence

These files preserve completed reports outside ignored build directories so a cloned or downloaded repository can rebuild the viewer without this workstation's caches.

- `v1-build-manifest.json` is the exact manifest from the two-build V1 reconstruction packet. Input and artifact hashes, compiler version and the **unqualified** status are retained. Executable images stay ignored; no firmware release is created here.
- `primary_reports/v1/` and `primary_reports/v2/` are preserved primary-agent report files originally stored under the respective CAD `_build/` directories. They remain reported/historical evidence; they do not supersede the current independent native review. Older V2 routing counts differ from the current three zone-to-zone entries.
- Current independent results are in [QUALITY_PORTABILITY.md](../../../reviews/codex/publication/QUALITY_PORTABILITY.md). Before/after CAD and presentation evidence remains in `reviews/codex/professionalization/`.

Byte-preserving Git attributes retain the input/report fingerprints across operating systems. `tools/quality/check_publication.py` verifies the committed native CAD inputs, displayed schematic exports and recorded firmware inputs. Its success establishes package consistency, not approval to manufacture or flash hardware.

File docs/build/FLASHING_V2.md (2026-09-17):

# V2: firmware readiness and staged bring-up

**There is no qualified V2 firmware image.** A separate [Stage A diagnostic](../../firmware_v2/README.md) now builds in `firmware_v2/`, with board identity, heartbeat and inactive actuator signals. It has not been run on hardware. [V2_FIRMWARE_PLAN.md](../../firmware/V2_FIRMWARE_PLAN.md) is a design plan, not an executable implementation. The reconstructed V1 ELF builds, but is **not approved for V2**. No V2 flash, boot, USB, radio, watchdog or actuator test has been run.

This page defines the connection and acceptance procedure for the existing Stage A diagnostic and later reviewed V2 images. Hardware power prerequisites and image review still apply before any programming or execution. Use each candidate's own manifest and image; the V1 image is not a substitute.

## Current pin contract to reconcile before code generation

The current hardware source is [v2_design.py](../../hardware/kicad_v2/tools/v2_design.py); compare it with the generated schematic, routed PCB and final assembly revision before using this table. The source is being developed and is not itself manufacturing approval.

| Function | V2 source connection | Firmware consequence |
|---|---|---|
| ESC | PC6/TIM3_CH1 → level shifter → J2 pin 1 | Start safe; verify both MCU and connector waveform |
| Servo | PA8/TIM1_CH1 → level shifter → J3 pin 1 | Start neutral only at the approved stage |
| Radio | PA0 TX, PA1 RX; reset PA3 | Acknowledged configuration, reset recovery, model/baud confirmation |
| GNSS | PC10 TX, PC11 RX; PPS PB0 | Dedicated UART; PB0 **input**, not V1's driven-low GPIO |
| IMU | PB6 SCL, PB7 SDA; interrupt PB5 | Driver and measured sensor identification required |
| Battery ADC | PA2; R31 47 kΩ / R32 6.8 kΩ in current source | Use actual divider/calibration, not the older 30 kΩ / 10 kΩ plan |
| Current ADC | PA4, current-sense output | Scale from actual gain/shunt and calibration |
| USB | PA11 D− / PA12 D+; divided VBUS at PA9 | Resolve VBUS-sense handling with selected USB stack; USB/CAN pin conflict |
| Link/fix/fault LEDs | PC1 / PC2 / PC3 | Power LED is hardware-wired, not a PC0 firmware LED |
| BOOT0 | U1-60 → R16 pull-down | No boot jumper appears in current net source; do not assume one exists |

The V2 plan and requirements still disagree in places: CRC-8 versus CRC-16, packet encoding/version flags, battery-divider values, and USB/console assumptions must be reconciled before implementation. Binary data through a line-oriented AT interface requires an explicit framing/escaping contract and tests. Treat promised latency and state transitions as requirements until measured.

## Debug connection

V2 keeps the STM32F446RET6 and uses **J7** for SWD. Electrical numbering below is from the current hardware generator. Verify the footprint, pin-1 mark, cable orientation and final schematic on the actual assembly; never infer physical position from this table alone.

| J7 pin | Signal | MCU package pin | Use |
|---|---|---|---|
| 1 | +3V3 | VDD rail | Target voltage reference |
| 2 | SWDIO | U1-46 / PA13 | Probe SWDIO |
| 3 | GND | Ground | Probe ground |
| 4 | SWCLK | U1-49 / PA14 | Probe SWCLK |
| 5 | GND | Ground | Ground |
| 6 | SWO | U1-55 / PB3 | Optional trace |
| 7 | NC | — | Leave open |
| 8 | NC | — | Leave open; differs from V1's TDI |
| 9 | GND | Ground | Ground |
| 10 | NRST | U1-7 | Probe reset |

Use the [V1 procedure](FLASHING_V1.md) sections 2–4 for adapter mapping, reference-voltage checks, programmer installation, serial selection and two main-Flash backups, substituting **J7/U1 and a `bench_v2_...` record folder**. Do not use its V1 image path. Even a nominally blank board gets an identity/option-byte record. Keep ESC/servo harnesses and unnecessary modules disconnected. Validate V2 assembly power rails first; +3V3 on debug pin 1 is not permission to power the board from a probe.

USB-C is not currently a tested flashing path. A physical USB connector does not establish a working CDC application, ROM-DFU entry route, or power path. The current source places VBUS on the connector/ESD/sense network; it must not be assumed to power the board's main rails. Use SWD for initial bring-up, with the validated board power source.

## Images to develop, in order

| Stage | Deliverable | Required evidence before the next stage |
|---|---|---|
| A: board identity | Implemented CMSIS diagnostic with preserved ST startup/linker inputs and a checked V2 pin contract; actuator pins remain inactive. No V2 `.ioc` exists; CubeMX integration is future work. | Build evidence exists; image/revision review, SWD connect/reset and measured rails remain required before hardware acceptance |
| B: safe outputs | PWM startup, disarmed state, timeout supervisor, watchdog and reset handling | Instrument captures at MCU and connector; safe first pulse, boot/brownout/reset, timeout and re-arm tests |
| C: radio/control | Radio driver + common handset protocol and parser tests | Module/version/settings readback; malformed/old/wrong-sender packets rejected; measured command age and link-loss behavior |
| D: navigation/power | GNSS validity/age, PPS, IMU, ADC calibration | Sensor disconnect/stale-data behavior; no traffic mixed into GNSS; voltage/current sweep |
| E: multifunction profiles | Explicit RC, telemetry and handheld messaging profiles | Profile identity on screen/log; RC scheduling protected from message bursts; reconnect, mode-switch and rollback tests |

The first image should prove pins, clocks and diagnostics while holding actuator outputs inactive. Defer autonomous navigation and unrestricted messaging until the control supervisor and firmware/hardware contract are tested. The next implementation must specify its exact radio-module model, supported AT firmware, antenna/band and regional operating profile; this document does not claim range or control latency.

## Programming once a V2 candidate is reviewed

1. Complete the staged image's build manifest and review source revision, V2 board revision, pin map, option-byte policy, radio profile and startup output behavior. Have a rollback/known diagnostic image and verify its hash.
2. Follow the two-backup/read-protection procedure in [V1 flashing](FLASHING_V1.md) for the actual V2 MCU. Record option bytes separately; main-Flash backup does not include them.
3. In CubeProgrammer choose SWD, the recorded probe serial, 1000 kHz, Under Reset and Hardware Reset. Open the **V2 candidate ELF/HEX** named in its manifest. Check addresses against its V2 Flash linker before programming. Select verify-after-programming; leave automatic execution disabled. Program and require a successful verification log.
4. Read back the exact BIN length from the manifest's load address and compare SHA-256 against that BIN. This assumes a contiguous Flash image as explicitly declared by that build; do not reuse `0x08000000` blindly if a later V2 bootloader changes the memory layout.
5. Release reset deliberately, with loads physically disconnected and probes already attached. Measure startup waveform and supply current. Archive programmer, readback and scope evidence with the manifest.
6. If verification or first execution fails, leave loads disconnected. Check supply/reset/debug wiring and candidate identity, then reconnect under reset. Restore only the verified image for that board with verification/readback; do not change protection or erase-all as a connectivity fix.

The CLI equivalents are the connect/backup/write/verify/readback sequence in V1, substituting the V2 candidate and its manifest addresses. The [Stage A guide](../../firmware_v2/README.md) names its existing build outputs. A successful Stage A build does not release the present assembly for power or execution; complete the electrical corrections, candidate review and bench prerequisites first.

## Acceptance record and release gate

For stages B/C, test without actuators: power cycling, reset during radio traffic, brownout, watchdog starvation, loss of handset, stale/duplicate commands, malformed frames, wrong sender, radio reset, and reconnect at nonzero throttle. Record measured response time, expected state, both output widths and any unintended startup pulse. The proposed 1 s timeout/20 ms response and watchdog limits must be reconciled with the final requirements and measured; they are not existing behavior.

Handheld communication needs its own data-delivery, pairing/authentication, congestion, UI, power-management and regional-radio requirements. Do not let a messaging mode inherit the authority to arm an RC actuator implicitly. CRC detects transmission errors; it does not authenticate a sender.

Every release record must state board revision, assembly/rework, firmware revision and SHA-256, compiler and build recipe, protocol/profile version, calibration, programmer/probe, backup/rollback identity and passed bench cases. Until that evidence exists, label every V2 image **development / loads disconnected**.

Smallest next step: resolve the electrical power/IMU/interface holds, review the existing Stage A diagnostic and record its bench acceptance before implementing Stage B. Existing V1 sources stay preserved.

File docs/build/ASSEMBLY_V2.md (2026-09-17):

# V2 vehicle-node assembly preparation

The current V2 is a vehicle-node design draft. It is the starting point for the multifunction boat/ground-vehicle platform; it does not contain the handheld's display, controls, voice codec or complete communication hardware. Assembly planning can proceed from this packet, while fabrication waits for a recorded design release.

## Assembly references

V2 top assembly pad map

[Top map](../../hardware/manufacturing/v2/assembly_top.svg) · [Underside map](../../hardware/manufacturing/v2/assembly_bottom.svg) · [BOM review](../../hardware/manufacturing/v2/bom_review.csv) · [Orientation review](../../hardware/manufacturing/v2/orientation_review.csv) · [Position reference](../../hardware/manufacturing/v2/positions_review.csv)

The maps come from the embedded footprints and pads in the existing PCB file. Orange indicates electrical pad `1`/`01`. For each IC, connector, diode, LED, transistor and electrolytic capacitor, match the exact manufacturer's package marking and pin/polarity definition to the electrical pad map. A pin-1 marker is not a universal cathode/positive mark. Grey outlines represent pad envelopes, not body/courtyard dimensions. Use the underside view for bottom-side work; its visual mirror does not change the CSV coordinate convention.

The draft has 118 PCB items, including 7 bare test points and 4 mounting holes. Those 11 features are not purchased components. Parts grouped in the original BOM may share a description from the first reference in the group; use the schematic to identify each reference's circuit function.

## Freeze the assembly variant

| Choice | References | Decision before ordering |
|---|---|---|
| On-board 5 V converter | U3, R6, C7, L2, R8, R9, C8, C9, C10, D4 | Confirm BEC input, VSERVO sources, back-feed behavior and the complete population choice |
| LSE clock | Y2, C27, C28 | Confirm firmware clock use, exact crystal/load selection and complete population choice |
| GNSS connector | J5 | Check selected MPN's body/mating geometry against the generic footprint |
| SWD connector | J7 | Check keyed Samtec variant, pin 1 and mechanical envelope |
| TVS / OR-ing diode ordering | D1, D4, D9 | Confirm full manufacturer ordering codes and circuit voltage/rating suitability |
| Radio and GNSS modules | External to the controller BOM | Select exact modules, pinouts, antennas and harnesses |

The candidate import files exclude held population choices. They are not a complete kit until the decisions above and [other external hardware](../../hardware/manufacturing/v2/external_parts_review.csv) are resolved.

## Release checks before fabrication

- [ ] Freeze the intended V2 scope and revision: boat, Ackermann, differential drive and fleet functions must map to actual interfaces and firmware requirements.
- [ ] Resolve the electrical review, including power protection and rail-source behavior, IMU supply/interface requirements, radio compatibility and actuator outputs.
- [ ] Run fresh ERC, PCB DRC including unconnected items, schematic/PCB parity, and BOM/PCB reference checks on the exact files to be released. Archive those outputs with input hashes. Old draft summaries are not current validation.
- [ ] Review buck-converter loops, fine-pitch grounding, USB routing, clocks, antenna placement and return paths. A clean DRC alone does not establish functional layout quality.
- [ ] Approve package land patterns, connector mechanics, pin-1/polarity marks, accessibility, enclosure/mounting and all population options.
- [ ] Confirm fabricator stack-up, outline, drill, copper, finish and stencil/assembly requirements. Inspect the final plotted layers and drill registration.
- [ ] Have the assembler review every orientation-sensitive reference. Convert raw KiCad rotations/origin to its centroid convention and approve a first-article drawing.
- [ ] Sign the release record before submitting fabrication or assembly files. This packet does not supply that sign-off.

## First-article assembly and test sequence

1. **Incoming inspection.** Record board serial/revision and quote/reel labels. Check PCB dimensions, drill registration, mask openings and connector fit. Reconcile delivered MPNs and approved substitutions with the frozen population list.
2. **Assembly preparation.** Use the approved stencil and the component manufacturers' soldering profiles. Assemble fine-pitch packages with the chosen process and inspect accessible joints; plan inspection for the IMU's hidden pads. Finish larger connectors according to the agreed assembly process.
3. **Unpowered checks.** Verify polarity and pin-1 orientation using the signed table. Inspect for bridges. Measure rail-to-ground observations, input path, VCAP return, actuator/logic isolation and selected power-source paths against the approved schematic.
4. **Power-only verification.** Keep modules and motion hardware disconnected. Use the approved voltage/current-limit plan; capture inrush, rail voltages/ripple, current-sense behavior and thermal observations. Record acceptance limits from the released design rather than inventing them during test.
5. **MCU and clocks.** Verify reset/BOOT, SWD identification, firmware hash and both required clocks. Record VCAP and supply startup observations. Confirm USB/debug behavior without sharing the GNSS command path.
6. **Interfaces.** Check actual radio/GNSS pinouts and supply levels before connection. Log radio identification/configuration acknowledgement, GNSS update rate/PPS and IMU identity/calibration. Validate the chosen antenna location in the assembled enclosure.
7. **Unloaded control.** Scope PWM and output levels through startup, reset, arm/disarm, link loss, stale/corrupt packets and watchdog/fault recovery. Verify a recovered link cannot silently re-arm.
8. **Controlled loads.** Test the selected servo/BEC supply arrangement, then restrained actuators and each vehicle profile. Capture power dips, resets, current readings and output behavior. Proceed to a five-board build only after the first article passes the recorded criteria.

The script produces assembly references and quantity checks. It does not perform any of these bench tests. Keep each measurement and decision attached to the exact board and firmware revision in the [handoff record](PROCUREMENT_HANDOFF.md).

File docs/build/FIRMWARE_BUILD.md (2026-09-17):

# Firmware build and artifact provenance

Status: **V1 software build verified; V1 hardware qualification unrun; V2 firmware not implemented.** Last checked 2026-09-17. Start here before [V1 flashing](FLASHING_V1.md) or [V2 bring-up](FLASHING_V2.md).

## What exists

The preserved `firmware/` tree contains STM32F446RE HAL/CMSIS sources, startup assembly, a Flash linker script, a RAM linker script, and `BoatTHISTIMEITSDIFFERENT.ioc`. It does not contain a retained CubeIDE `.project`/`.cproject`, original Makefile, or a known deployed firmware image. Those IDE files and build outputs are ignored by the repository. The new [build helper](../../firmware/tools/build_v1.py) reconstructs an explicit GCC recipe around the existing files; it does **not** establish bit-for-bit equivalence to firmware previously used on a boat.

| Item | Reconstructed V1 build |
|---|---|
| Device | STM32F446RET6, Cortex-M4F |
| Application Flash | `0x08000000`, 512 KiB; no application bootloader offset |
| SRAM | `0x20000000`, 128 KiB |
| Linker | `firmware/STM32F446RETX_FLASH.ld` |
| Startup | `Core/Startup/startup_stm32f446retx.s` |
| ABI | Thumb, Cortex-M4, FPv4-SP-D16, hard float |
| Defines | `USE_HAL_DRIVER`, `STM32F446xx` |
| C / optimization | GNU11, `-Og`, debug information, section garbage collection |
| C library | newlib nano; `_printf_float` **and** `_scanf_float` linked explicitly for existing GPS formatting/parsing |
| Included code | All current `Core/Src/*.c`, vendored HAL `Src/*.c`, startup assembly |
| Original Cube package declaration | STM32Cube FW_F4 V1.28.3 in `.ioc`; vendored files are the actual build inputs |

Memory sizes and device family are consistent with the [ST STM32F446xC/E datasheet](https://www.st.com/resource/en/datasheet/stm32f446re.pdf). The Flash linker is authoritative for this recipe. Do not substitute the RAM linker for a persistent flash image.

## Tools and commands

Required: Python 3.9+ standard library and GNU Arm `arm-none-eabi-gcc`, `arm-none-eabi-objcopy`, `arm-none-eabi-size`. GCC 11 or later is needed for this linker's `READONLY` syntax. The tested compiler was **GNU Tools for STM32 13.3.rel1**, bundled with STM32CubeIDE 1.19.0. No packages are downloaded by the helper.

From the repository root:

```text
python firmware/tools/build_v1.py preflight
python firmware/tools/build_v1.py build
```

The helper uses `--toolchain BIN_DIRECTORY`, then `ARM_GCC_BIN`, then PATH, then installed CubeIDE tools under `C:/ST` on Windows. Set `--toolchain` explicitly in CI to pin the intended compiler; automatic discovery is convenient locally and is not a version lock.

On the verified Windows host, `python` was absent from PATH and `py -3` reported no installed Python. The working commands were:

```powershell
$Python = 'C:\Users\Jay\.cache\codex-runtimes\codex-primary-runtime\dependencies\python\python.exe'
& $Python firmware/tools/build_v1.py preflight
& $Python firmware/tools/build_v1.py build
if ($LASTEXITCODE -ne 0) { throw 'Firmware build failed' }
```

`preflight` prints JSON with tool paths, compiler version, source list, SHA-256 hashes and known warnings. It writes no files and accesses no hardware. `build` always recompiles, invokes only compiler/binutils, and writes below `firmware/Debug/`, an already ignored folder. It neither runs CubeMX nor changes the C, headers, startup or `.ioc`. It rejects an output path outside a subdirectory of `firmware/Debug/`. Do not run it concurrently against the same output directory.

## Outputs and interpretation

Default output: `firmware/Debug/reproducible_v1/`.

| File | Purpose |
|---|---|
| `boat_v1_unqualified.elf` | Address-bearing executable and debug information; preferred programming input after hardware gates |
| `boat_v1_unqualified.hex` | Address-bearing Intel HEX |
| `boat_v1_unqualified.bin` | Raw Flash image; requires address `0x08000000` when programming |
| `boat_v1_unqualified.map` | Link placement and memory review |
| `manifest.json` | Compiler, source hashes, artifact hashes, vectors, build state and warnings |
| `build.log` | Exact argument arrays and all compiler/linker output |
| `size.txt` | GNU size summary |

Use artifacts only from a manifest whose status is `build_pass_unqualified`. A failed attempt records `build_failed`; earlier files may remain in its output directory and must not be mistaken for a successful current build. Archive the manifest and log with every candidate image.

The helper checks binary length, SRAM stack bounds/alignment, Thumb reset vector within the image, and unchanged inputs before/after compilation. These are software sanity checks, not peripheral tests or a safety qualification.

The verified build used 36,528 bytes of the Flash region and 4,496 bytes of the RAM region. GNU size reported text/data/bss = 36,044 / 472 / 4,024 bytes. The RAM figure includes reserved heap/stack space; it is **not** a measured worst-case runtime stack/heap usage. Three warnings came from unused `Banks` parameters in the existing ST `stm32f4xx_hal_flash_ex.c`; the build completed without errors.

## Preserve behavior and review known drift

Do not regenerate the V1 project in place. Current C initializes TIM3 to 1000 microseconds, while `.ioc` specifies 1500. Main-loop application code and IRQ setup also differ from generator assumptions. A regenerated project may lose behavior even if it compiles. If CubeIDE integration is needed, import the sources into a separate project, reproduce this recipe, compare generated diffs, and preserve these hashes before accepting changes.

The compiled image retains the documented V1 issues: no link-loss stop, no explicit arm/disarm, PWM/header naming mismatch, GPS freshness/parser limits, and PB0 configured as an output on the GPS connector. Compilation does not fix them. Follow the [V1 design review](../V1_DESIGN_REVIEW.md) and [firmware review](../research/FIRMWARE_REVIEW_NOTES.md).

## CI and release boundary

CI should run preflight and build on every firmware/tooling change, retain `manifest.json`, `build.log`, `size.txt`, ELF/HEX/BIN/map, and display `UNQUALIFIED V1` in the artifact name. Pin Python and GNU Arm versions in the CI environment. On a runner with both on PATH the two commands above are sufficient; no IDE or programmer is needed. Hardware flashing must not occur on an ordinary pull-request runner.

Before distribution as a qualified release, record the source revision and manifest hash, exact target board revision, assembly rework, radio model/firmware, build recipe/toolchain, hardware acceptance results, operator and rollback image. A green compile is only a build result. V2 requires a separate target, pin contract and qualification record; renaming this V1 binary does not provide them.

See [firmware handoff](FIRMWARE_HANDOFF.md) for actual runs, reproducibility results and the smallest next step.

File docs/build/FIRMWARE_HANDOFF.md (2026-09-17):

# Firmware work handoff — 2026-09-17

Outcome: **preserved V1 sources compile and link through a new non-flashing recipe; no qualified V2 image exists.** No functional firmware, `.ioc`, hardware, shared coordination file or Git state was changed by this work. No probe enumeration, connection, reset, erase, program, option-byte write or hardware test was executed.

## Added files

- [FIRMWARE_BUILD.md](FIRMWARE_BUILD.md): actual inputs/toolchain, reproducible commands, artifacts, known limitations, CI/release boundary.
- [FLASHING_V1.md](FLASHING_V1.md): assembly gate, verified electrical debug pin map, two backups, option-byte record, program/verify/readback, first instrument-only execution and rollback.
- [FLASHING_V2.md](FLASHING_V2.md): current J7 map, no-image status, V1 incompatibility, firmware/hardware contract gaps, staged implementation and future programming acceptance.
- [build_v1.py](../../firmware/tools/build_v1.py): Python standard-library preflight/build; hashes inputs, captures commands, exports ELF/HEX/BIN/map, checks vectors and records success/failure. Output is confined to subdirectories of the already ignored `firmware/Debug/` tree.
- This handoff.

## Actual software checks

Executed from the repository root on Windows using Python **3.12.14** at:

```text
C:/Users/Jay/.cache/codex-runtimes/codex-primary-runtime/dependencies/python/python.exe
```

The host's `py -3 --version` reported `No installed Python found`; `python`, GNU Arm tools and CubeProgrammer were not on PATH. The helper discovered these existing tools without an installation/download:

```text
C:/ST/STM32CubeIDE_1.19.0/STM32CubeIDE/plugins/com.st.stm32cube.ide.mcu.externaltools.gnu-tools-for-stm32.13.3.rel1.win32_1.0.0.202411081344/tools/bin
```

Compiler banner: `arm-none-eabi-gcc.exe (GNU Tools for STM32 13.3.rel1.20240926-1715) 13.3.1 20240614`.

| Command (using the Python executable above) | Observed result |
|---|---|
| `firmware/tools/build_v1.py preflight` | Exit 0; `software_preflight_pass`, 23 compilation sources, 95 hashed inputs |
| `firmware/tools/build_v1.py build` | Exit 0; `build_pass_unqualified`; generated default outputs |
| `firmware/tools/build_v1.py build --out firmware/Debug/reproducible_v1_repeat` | Exit 0; independent second output directory |
| SHA-256 comparison of two builds' BIN, HEX and ELF | All three identical on this host/toolchain/source snapshot |
| `firmware/tools/build_v1.py preflight --toolchain firmware/tools/nonexistent-toolchain` | Expected exit 1 with clear missing-toolchain error |
| `firmware/tools/build_v1.py build --out firmware/Core/rejected-build-output` | Expected exit 1; forbidden source-directory output rejected before creation |
| Installed `STM32_Programmer_CLI.exe --help` | Exit 0, version 2.20.0; syntax for connect, read/upload, write, verify, halt and option-byte display inspected |
| Static documentation checks | Five PowerShell blocks parsed without executing them; all relative document links resolve |

Both builds reported these same existing HAL warnings: unused `Banks` argument at `stm32f4xx_hal_flash_ex.c:948`, `:1027`, `:1063`. No build errors. Each build's before/after source hashes matched, so the preserved inputs were stable through compilation.

## Generated result

Default output directory: `firmware/Debug/reproducible_v1/`. Repeat: `firmware/Debug/reproducible_v1_repeat/`. These are ignored local artifacts, not a committed firmware release.

| Measurement | Result |
|---|---|
| Flash region used / BIN length | 36,528 bytes |
| RAM region used | 4,496 bytes, including static data and linker heap/stack reservation |
| GNU size text / data / bss | 36,044 / 472 / 4,024 bytes |
| Initial stack | `0x20020000` |
| Reset vector | `0x08003569` (Thumb) |
| BIN SHA-256 | `9b90f0322089d997f1498ee634d4880005bd85fd5337d7a013a5609954239e17` |
| ELF SHA-256 | `612c82d7c2d4994003d509526d382328300dd505e0a6ef9520c9de8cd2939b0c` |
| HEX SHA-256 | `70efa56de33629a070fdc6c5b65b1a7b6e0b9aad8ebc2e5a84e30c1791957ff6` |

`manifest.json` contains individual input hashes and artifact hashes; `build.log` contains exact tool argument arrays. Map/log/manifest paths or timestamps can differ between directories; no cross-machine or cross-compiler bit-identical claim is made. The same-machine ELF/HEX/BIN repeat is the verified scope.

## Limits that remain

1. The historical deployed image and original IDE build metadata are absent. This recipe is a new reproducible reconstruction, not proof of the exact original binary.
2. V1 retains no link-loss failsafe or explicit arming, mirrored actuator-header naming, parser/GPS problems, and PB0 driven low at the GPS header. The build does not correct them. V1 power/VCAP/BOOT0 findings must be resolved on the actual assembly before power is applied.
3. Current C starts TIM3 at 1000 microseconds; `.ioc` says 1500. In-place regeneration is not part of this workflow.
4. V2 has a design plan but no firmware project/image. Its plan needs reconciliation against actual V2 nets (battery divider, USB VBUS sense, BOOT0 access, CRC/protocol decisions). It must not inherit a release claim from the V1 build.
5. All backup, flash, readback, waveforms, boot, UART, radio, USB, sensor, actuator and recovery instructions are hardware procedures awaiting execution. Programmer `--help` is not an ST-LINK connectivity test.

## Next small work packages

**Software-only next step:** integrate `preflight` and `build` in CI with a pinned GNU Arm 13.3.rel1 toolchain and Python version, uploading the unqualified artifacts plus manifest/log. It needs no hardware, IDE regeneration or programmer. The coordinating agent owns CI integration.

**V1 bench next step:** after documented assembly/power corrections, photograph and continuity-check JTAG1, then connect under reset and capture two matching 512 KiB backups plus option-byte display. Do not skip directly to programming.

**V2 development next step:** freeze a reviewed pin/protocol contract, then create a separate stage-A `firmware_v2/` diagnostic project with actuator outputs inactive. Prove build, SWD/identity and measured rails before adding PWM/supervisor, radio, sensors or handheld profiles.

## Primary references consulted

- [ST STM32CubeProgrammer MCU CLI](https://dev.st.com/stm32cube-docs/prog/2.23.0/en/docs/markup/CubeProg_Command_Lines.html), backed by installed 2.20.0 CLI help for the used syntax.
- [ST STM32F446xC/E datasheet DS10693](https://www.st.com/resource/en/datasheet/stm32f446re.pdf), device family/memory/debug reference.
- Repository sources: `firmware/Core`, `firmware/Drivers`, both linker scripts, `.ioc`, V1 pin atlas/evidence, V1 review, V2 requirements/firmware plan and `hardware/kicad_v2/tools/v2_design.py`.

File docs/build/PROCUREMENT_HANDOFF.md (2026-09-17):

# Procurement and assembly handoff

This packet makes the existing source BOMs easier to review, quote and assemble while preserving a clear distinction between the V1 boat and V2 vehicle-node draft. It has not created a distributor cart, purchase order, fabrication job or assembly order.

## Start here

1. Read [Ordering](ORDERING.md), then choose [V1 assembly/repair](ASSEMBLY_V1.md) or [V2 assembly preparation](ASSEMBLY_V2.md).
2. Open [run_manifest.json](../../hardware/manufacturing/run_manifest.json). It is the single generated run record: source hashes, selected board count, quantity totals, matching checks, release limitations and every output hash.
3. Review `holds.csv` and `external_parts_review.csv` for the chosen version. These are the missing decisions that a partial candidate quote cannot settle.

## Reproduce the packet

The exporter uses Python's standard library and KiCad 9's `pcbnew` bindings. It reads existing BOMs and PCB files, extracts embedded pad positions, and writes only `hardware/manufacturing/v1/`, `v2/` and the run manifest. It does not save CAD, refill zones, run another generator, access the network or place orders.

```powershell
& 'C:/Users/Jay/AppData/Local/Programs/KiCad/9.0/bin/python.exe' hardware/manufacturing/prepare_release.py --boards 1
& 'C:/Users/Jay/AppData/Local/Programs/KiCad/9.0/bin/python.exe' hardware/manufacturing/prepare_release.py --boards 1 --check
& 'C:/Users/Jay/AppData/Local/Programs/KiCad/9.0/bin/python.exe' hardware/manufacturing/check_package.py
```

Use the installed KiCad Python equivalent on another machine. Set `--boards 5` or another positive quantity for `distributor_candidates_selected.csv`; one-board and fleet-five files remain available. `--check` fails if an artifact is absent/stale. If CAD/BOM inputs change during extraction, generation fails rather than issuing a mixed snapshot. The rectangular-outline extractor deliberately fails if a later revision uses an unsupported profile; update and review it for that geometry.

Selection rules live in [procurement_policy.json](../../hardware/manufacturing/procurement_policy.json). Resolve a hold by reviewing the source part/footprint and its requirements, recording the decision, and updating the source or policy intentionally. Do not turn off all holds to make the order list look complete.

## What is verified

| Check | Meaning |
|---|---|
| BOM reference coverage | Each listed reference occurs once and exactly matches the PCB footprint reference set |
| Source quantity reconciliation | A grouped BOM quantity matches its references; the V2 TOTAL row is excluded and reconciles to 118 |
| Purchase-feature separation | Test pads, battery solder pads and mounting holes are retained in review data but never treated as purchased parts |
| Part identity preservation | Manufacturer/MPN text comes from the source BOM; no substitute or supplier SKU is invented |
| Selected/fleet counts | Per-reference counts drive one-board, selected-count and five-board candidate imports; no hidden spares |
| Snapshot stability | SHA-256/byte counts record inputs and outputs; the extractor detects concurrent source edits |
| Drawing geometry | Pad coordinates, pad 1, side and raw rotation are extracted from the PCB; outline dimensions exclude drawing stroke width |

The generation and reproducibility check passed for both boards. Independent package checks passed for one-board, three-board and fleet-five quantities, exact preserved MPN strings, held-part exclusion, manifest hashes, position coverage, SVG parsing and local document links. The final selected quantity is one board. Both top maps were rendered in a local browser and visually inspected; the crowded V1 radio-filter labels were adjusted and rechecked. Bottom maps identify that the source boards have no bottom-side footprint population.

Package bodies, machine rotation conventions and physical orientations remain separate checks. A generated pad map is not a verified assembly process. Current stock, prices, lifecycle, exact order suffixes, procurement availability, electrical sign-off, fresh ERC/DRC, copper integrity and bench operation are not certified by this packet.

## Release record to complete

| Field | Record before release |
|---|---|
| Product / use | Existing V1 repair, V2 first article, or later fleet build |
| Board revision / source hash | Exact frozen PCB, schematic and BOM inputs |
| Firmware | Source revision, toolchain, binary hash and tested configuration |
| Electrical/layout acceptance | Reviewer, date, closed issues, accepted exceptions and validation file links |
| Population | Fitted/DNP reference list and source/BEC/clock decisions |
| Parts | Final manufacturer/MPN, supplier SKU, substitutions, quantity and dated quote |
| Mechanical | Connector mating parts, harness drawings, pin-1/polarity sign-off, enclosure and mounting |
| Fabrication | Stack-up, dimensions/drills, copper, finish, manufacturing files and independent plot review |
| Assembly | Stencil/profile, approved centroid convention and first-article orientation review |
| Bench acceptance | Board ID, supply plan, measured rails/current/ripple, interface and failsafe records |
| Authorization | Named person and date accepting the final concrete order package |

No release field should be marked complete merely because a CSV was exported. The next engineering steps are to resolve the held selections and electrical/layout findings, produce a frozen first-article release, then use that reviewed package for ordering and assembly.

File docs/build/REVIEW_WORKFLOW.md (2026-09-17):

# Review workflow and acceptance gates

The local runner checks that schematic presentation changes preserve the captured electrical design, exports reviewable sheets, and records native ERC/DRC results. **A successful documentation review is not fabrication approval.** It does not run CAD generators, fill zones, update a board from a schematic, alter the primary project, or upload anything.

## Local commands

From the repository root, using the installed KiCad 9 Python on this workstation:

```powershell
& 'C:\Users\Jay\AppData\Local\Programs\KiCad\9.0\bin\python.exe' -m unittest discover -s tools/quality -p 'test_*.py' -v
& 'C:\Users\Jay\AppData\Local\Programs\KiCad\9.0\bin\python.exe' tools/quality/review.py --profile review
```

On another machine, Python 3.10+ is sufficient for the runner; set `KICAD_CLI` to a KiCad 9 executable or place `kicad-cli` on PATH. `--kicad-cli <path>` overrides discovery. Native checks also need the project libraries and installed KiCad symbol/footprint libraries referenced by their tables. Tests use only Python's standard library.

Each run creates a fresh timestamped directory under `reviews/codex/professionalization/quality-runs/`. Use `--output reviews/codex/professionalization/<unique-name>` for a chosen empty directory. Existing nonempty output directories are refused to prevent old exports being mistaken for new results. The runner exits 0 only if the requested gate passes; missing tools, invalid reports or incomplete execution produce a failed report.

Use `--design v1` or `--design v2` to limit the review; the default checks both. `--profile fabrication` requests the stricter readiness gate and currently returns failure. There is no ignore-warning, ignore-unconnected or waive-parity switch.

## What each gate means

| Evidence | Documentation/layout review | Fabrication readiness |
| --- | --- | --- |
| Stable captured inputs; CLI major version 9; complete run | Required | Required |
| Same parts, values, footprints and complete pin grouping as the pre-edit baseline | Required | Required |
| Preserved PCB/project/custom-rule bytes during this presentation-only change | Required | Inherited from review |
| Native ERC with all severities | Must have zero violations | Must have zero violations |
| Schematic page-coordinate anchors and box corners | Must fit on the declared page | Required, but insufficient for visual approval |
| SVG export for every sheet | Required | Required |
| DRC errors, unconnected items, parity differences, warnings/exclusions | Recorded separately, never hidden | All must be resolved; no automatic waivers |
| Text extents, overlap, readable labels, assembly information and fabrication/drill evidence | Human review still required | Explicit engineering and visual acceptance still required |

The final human/engineering acceptance is deliberately left pending by this runner. It never turns a passing command into permission to manufacture. Until a separate release record is reviewed, `fabrication` remains false even if the automated tests become clean. Known V2 unrouted connections are reported as actual failures of fabrication readiness; a documentation check can still pass while those failures remain visible.

The coordinate check tests actual top-level primitive anchors, wire vertices and explicit box corners. It **does not** measure rendered text glyphs or symbol extents, detect collisions, assess reading order, or judge engineering correctness. Review the exported SVGs at normal reading scale and inspect all sheets, especially connectors, power paths and MCU labels. Do not call this check an automatic visual-quality pass.

## Baseline identity and scope

The pre-edit capture is in `reviews/codex/professionalization/quality-baseline/`. Its manifest records SHA-256 hashes taken before and after copying 26 V1/V2 design files. Both original and copied hashes agreed. KiCad exported the baseline netlists from these copies before schematic professionalization.

Compact acceptance data lives in `tools/quality/baselines/v1.json` and `v2.json`. It includes the original input hashes, XML hashes, component identities and all physical pin groups. V1 uses the explicit `Allegro_RefDes` property; V2 uses native references where that property is absent. Isolated NC pins remain individual groups and are checked, not discarded. Net-name changes with identical pin membership are reported separately. A pin reassignment, missing isolated pin, part substitution, changed footprint or duplicate physical pin fails the check.

At capture, V1 contains 44 electrical components / 172 pins. V2 contains 114 electrical components / 361 pins; its 118-part physical BOM includes four mounting holes that are absent from the electrical netlist. A recorded Git HEAD describes context only: working-file hashes identify the actual captured input.

`capture_baseline.py` is an explicit one-time utility, never invoked by review or CI. It refuses to overwrite the canonical baselines. A deliberate electrical design change needs a reviewed new baseline and a documented reason; regenerating the acceptance baseline merely to make a failing test pass defeats the check.

## Reports and evidence transfer

Every completed or failed run saves `review.json` and `REVIEW.md`. The JSON contains command arguments, stdout/stderr, tool version, Git context, source hashes, output hashes, separate gate results and detailed counts. Per-design folders contain exported netlists, connectivity comparisons, ERC, DRC with schematic parity, page-coordinate results and SVGs. Native tools operate on the copied `inputs/hardware/...` tree. The runner checks both the original files and copied inputs for unexpected mutations.

A clean handoff records:

1. The report path and exact source hashes, plus the released revision if one exists.
2. Whether the **review** gate passed and why **fabrication** remains open.
3. ERC counts, DRC errors/warnings, unconnected count and schematic-parity count as separate quantities.
4. Which rendered sheets were visually inspected, by whom, and remaining readability issues.
5. The next bounded correction and its file owner. Do not substitute a moving checkout for the recorded inputs.

## Generator dispatch regression

The existing V2 command dispatcher was found to regenerate the PCB, project and BOM even for a `sch` request. Once the dispatcher is fixed, this explicit regression command tests it in a separate copy:

```powershell
& 'C:\Users\Jay\AppData\Local\Programs\KiCad\9.0\bin\python.exe' tools/quality/check_generator_dispatch.py
```

The command copies the generator and libraries, runs only `gen_v2.py sch` inside that copy, and compares the copied PCB/project/BOM before and after. It also checks that those working-tree files remained unchanged. This tool is separate from the read-only review runner and is never invoked implicitly. Its report does not replace the netlist/ERC/render checks.

## Optional GitHub Actions

Publication update: `.github/workflows/repository-checks.yml` adds automatic portable checks on pushes and pull requests. It runs the 18 acceptance-logic tests, committed evidence/portfolio checks, manufacturing reconciliation, atlas checks and a viewer rebuild. A green repository check establishes package consistency only. It does not erase the existing V2 ERC/DRC findings, run a programmer or approve fabrication. The native/manual workflow below remains separate.

`.github/workflows/design-review.yml` is a **manual-only definition**. No workflow was activated or pushed as part of this work. If the repository owner later enables and dispatches it, the standard-library tests run on a hosted Linux runner. Native KiCad checks are separately opted into and require a trusted self-hosted Windows runner labeled `kicad-9`, with the KiCad 9.0 per-user install path shown above. Adjust that path deliberately for another installation. Workflow permissions are read-only; there is no deployment step. It uploads reports even when a check fails.

The separate `run_firmware` option compiles **preserved V1 only** on a trusted self-hosted Windows runner labeled `gnu-arm-13-3`. It pins Python 3.12.14 and verifies the recorded GNU Tools for STM32 13.3.rel1 / GCC 13.3.1 compiler banner before building. Set `ARM_GCC_BIN` on that runner if the helper cannot discover the matching installed toolchain. It runs `firmware/tools/build_v1.py preflight` and `build --out firmware/Debug/ci_v1_unqualified`, then verifies the unqualified/software-only manifest state and preserves image/log/map/hash evidence. There is no programmer command, hardware connection or V2 build claim. See [firmware build](FIRMWARE_BUILD.md) and [actual firmware handoff](FIRMWARE_HANDOFF.md) for the two completed local builds, vector checks, matching BIN/HEX/ELF hashes and remaining defects. This workflow does not turn those images into a deployable release.

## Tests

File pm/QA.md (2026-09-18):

# Viewer delivery verification — 2026-09-17

## Current isolated IMU candidate edition

The V2 Design selector includes the annotated 1.8 V IMU candidate with explicit pending PCB integration. Its project link opens the isolated candidate; the live PCB link is omitted for that view. Desktop 1440 x 1000 and phone 390 x 844 checks pass candidate selection/image load, guide opening, correct project link and no page overflow or browser errors. [Results](../reviews/codex/imu_interface/viewer_check.json).

The changed A2 Navigation SVG was rasterized with CairoSVG and visually inspected after correcting supply-label spacing, annotation length and title-block scope. [Visual evidence](../reviews/codex/imu_interface/visual_review.json). Packaging contains 75 documents, 53 images and 224 indexed paths; 236 local HTTP links pass. The candidate is not included in the live PCB or buying lists.

## Current application and diagnostic edition

The viewer reads the integrated V2 board's [native review](../reviews/codex/design_completion/native-review/REVIEW.md), the [Stage A build manifest](../firmware_v2/evidence/stage_a_build.json), five application guides and six component-limit findings. V2 now has zero unconnected PCB items; the strict native review and hardware release gates remain failed/open. Purchasing data reflects 74 candidate / 33 held / 11 bare-feature V2 references.

Headless Edge checks at 1440 x 1050 and 390 x 844 passed: five guide cards, V2 guide dialog, application search, diagnostic instructions, no browser errors and no page-level overflow. [Recorded results](../reviews/codex/design_completion/ui/application-ui.json) and desktop/phone screenshots preserve the checked view. The six electrical findings use expandable cards for phone readability. The server exposes reviewed V2 source and evidence paths, while firmware build outputs remain unavailable over HTTP. Direct-file mode and physical hardware behavior were not tested.

Earlier counts and missing-V2-image statements below describe their dated snapshots. Current source/input hashes are in [status.json](status.json). The clean source archive rebuilt 74 documents, 52 images and 222 indexed paths; live HTTP validation passed 234 paths. The [current handoff](../reviews/codex/design_completion/HANDOFF.md) records the 27 passing tests, evidence checks and refreshed PCB preview provenance.

## Earlier portable publication edition

The viewer now uses the publication native review (52 active CAD inputs), tracked V1 build evidence and tracked primary reports. All fifteen schematic inputs reproduce without the old local build cache. A clean staged-source archive rebuilt and validated the viewer with 60 documents, 200 indexed paths, 52 drawings/images and two valid scripts. Its revision is explicitly `source-archive`. The local HTTP check passed all 212 links and blocked-path probes. No new browser interaction test or hardware test is implied; desktop/mobile behavior was checked in the preceding edition below.

## Earlier build and programming edition

This update supersedes the earlier limitations below where explicitly addressed. The Build & program section presents separate V1/V2 cards, candidate imports for one/five boards, held and external parts, orientation/position evidence, four assembly maps and the build/flashing guides. It displays manifest freshness and the latest numbered native review with its strict failed gate visible. Copied review inputs are excluded from the document library.

The integration subtask checked desktop 1440 × 1050 and mobile 390 × 844 in headless Edge: all four assembly images loaded, the flashing document dialog opened, verification headings rendered, no browser errors and no page-level mobile overflow. At that checkpoint, all 192 HTTP links and blocked-path probes passed. After restarting the server and adding final documentation, packaging and all **203 HTTP links** passed; the snapshot has 63 documents, 191 indexed paths, 52 design images/PDFs and two valid embedded scripts. No inputs changed during capture. No external hosting or actual hardware programming was performed.

Current schematic PDFs/SVGs were separately rendered and visually reviewed on all fifteen pages. See [visual review](../reviews/codex/professionalization/VISUAL_REVIEW.md). Fresh independent CAD evidence is candidate 04; V1 compile results concern the preserved source and do not qualify its existing behavior. The V2 image remains unavailable.

## Earlier viewer-only checkpoint

Scope: local project viewer and portable V1 evidence. Repository branch `v2-design`, captured HEAD `a6316e9216cc55656e3fbb7c4f173895151ac4ff`. Primary CAD/tool working changes remain outside this packet. Input hashes and capture time are in [status.json](status.json); those hashes include uncommitted input bytes, not just HEAD.

## Checks completed

- `node pm/tools/build.mjs`: successful; no hashed inputs changed during capture. Generated data contains 44 V1 parts, 67 V2 component groups (118 physical parts), 12 V1 atlas entries, 35 findings, 45 requirements and 52 image/PDF views.
- `node pm/tools/validate.mjs --http`: successful. Both inline scripts parse; executing only the data assignment reproduces status.json exactly. Indexed paths and independent evidence exist; local HTTP evidence links return 200. Atlas citations are embedded. V2 aggregate TOTAL row is excluded and source quantities reconcile. Unique finding IDs checked.
- Browser at 1280 × 900 and 390 × 844: overview renders, phone view has no page-level horizontal overflow (document width equals viewport; individual tables/nav can scroll).
- V1 BOM search U3 → Inspect → STM32 manufacturer reference; V2 R1240 search → U2 → explicit R1240 datasheet mapping.
- V2 top render loads at 1992 × 1120; Power schematic SVG loads and zoom reaches 350%.
- V1 LoRa atlas opens with five pins; a preserved netmap citation opens at its source line.
- Findings search REQ-CTL-01 → acceptance detail shows the actual 1.0 s default and 20 ms response requirement from the source document.
- Verification displays historic V1 evidence separately from working primary reports. Evidence arrays render as usable links.
- HTTP Refresh reports success. Export handoff now opens reviewable Markdown with a Save link and a copyable text fallback; its content and current revision were checked.

## Repairs made during verification

Embedding JSON through a replacement string expanded firmware dollar sequences and broke HTML. A replacement callback now preserves bytes; the data equality check catches recurrence. V2 TOTAL was formerly counted as a component. Datasheet mapping now uses explicit MPNs rather than a fuzzy prefix. Atlas evidence buttons now open embedded sources and scroll to cited lines; ignored netmap/XML artifacts were preserved under docs/atlas/evidence by the atlas packet. Long stat text wraps on phone screens. Phase status text comes from the current primary report; manual intake dispositions are labelled as such.

## Limits and discrepancies

- Browser automation policy blocks file:// navigation. Direct double-click mode was therefore not exercised in this browser. The page embeds its scripts/data, has no startup fetch or third-party assets, and passes packaging checks; HTTP mode was exercised directly.
- The in-app browser did not deliver a download event for the former automatic Blob download. The revised export exposes the complete Markdown for copying and a Save link. Actual saved-download completion is not claimed.
- Complete manufacturer datasheet coverage, V2 connector pages and independently verified V2 CAD remain later packets.
- Current docs/BOM_V2.csv has 67 numbered component rows; REPORT.md says 68. Both agree on 118 parts. The viewer displays this discrepancy. Working drc.rpt and drc_all.rpt also differ (3 versus 2 unconnected entries); the report describes two. Resolve against a stable hashed V2 snapshot.
- V1 S2 results apply only to 639e08f. The 139 native parity warnings describe classified metadata differences; no electrical mismatch was found. No-change Update-PCB behavior, V5 drill sizes, independent full-film XOR, firmware compilation and bench operation remain unverified.
- REQ-CTL-01 says 1.0 s default command loss, while PROMPT_FOR_CODEX.md says 500 ms. Resolve the requirement before voice/RC coexistence acceptance tests.

Next bounded packet: independently snapshot and verify V2 ERC/DRC and inventory, then inspect one power/control subsystem. Preserve Allegro evidence and primary CAD/firmware ownership throughout.

## IMU placement review - 2026-09-18 UTC

Local viewer: 76 documents, 54 images, 228 indexed paths. Desktop 1440 × 1000 and phone 390 × 844 checks passed placement-map loading, isolated project/PCB links, failed-native-check disclosure, zero page overflow and zero script errors. All 228 indexed local HTTP paths passed. The long view selector now shrinks within its label on phones. Placement evidence is deliberately a failed electrical integration gate: 136 native errors, preserved original copper and no new pad assignments. See reviews/codex/imu_placement/viewer_check.json and http_check.json. Hosted CI and hardware acceptance are separate.

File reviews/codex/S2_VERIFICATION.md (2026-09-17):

# S2 — independent verification of released V1

**Verdict: connectivity verified, with explicit evidence limits.** At released commit `639e08fe56c38d54becf086f4fd86ec20ecfcb90`, the source netlist, KiCad schematic and PCB agree on every physical pin and part. ERC has zero violations; PCB DRC has zero errors and zero unconnected items under the released rules. An additional native schematic-parity check finds **139 warnings**, so this report does not declare complete schematic/PCB synchronization. V5 hole centers match, but the supplied drill cannot establish V5 finished-hole sizes.

**Interpretation clarified after the primary's 2026-09-17 review:** the 139 warnings are classified value/name metadata differences, not failed electrical connectivity. They leave the no-change Update-PCB workflow unverified; they do not block use of this reconstruction as a documented V1 baseline. The initial viewer summary's global "transfer gate blocked" label was too broad and has been narrowed. Raw evidence and counts are unchanged. Any primary correction in a later revision needs a separate check before closing the historic finding.

This is a historical V1 review of the exact released commit, completed 2026-09-17 UTC. It does not assess the later `v2-design` branch or imply that these findings remain present in later revisions. No primary generator ran, no CAD input was edited, and no Git history was changed by this reviewer.

## Gates and evidence

| Gate | Result | Independent result |
| --- | --- | --- |
| Input identity | PASS | Files exported from the commit using `git show`; all recorded SHA-256 hashes still match after verification. |
| Net/pad membership | PASS | 44 parts and 172 physical pins in source, schematic and PCB; exact equality of all 31 multi-pin nets, singleton VBAT and 37 individually isolated NC pins. No duplicate pin membership. |
| Symbol/footprint identity | PASS | Explicit `Allegro_RefDes` fields used for both CAD representations. All component references, footprint libraries and symbol/footprint paths agree. |
| ERC | PASS | KiCad 9.0.7, `--severity-all`: 0 violations, root plus 7 functional sheets. |
| DRC errors/routing | PASS WITH WARNINGS | 0 errors, 0 unconnected; 67 warnings under the released project/custom rules. |
| Native schematic/PCB parity | OPEN | 139 warnings, fully classified below. Electrical pin-set agreement does not remove these metadata/synchronization differences. |
| V5 hole centers | PASS | 53/53: 26 drilled pads and 27 vias match round dark flashes common to both V5 copper films. |
| V5 drill dimensions | UNVERIFIED | Supplied BOATCREW drill equals V4 data except the `;FILE` header. V5 diameter/plating provenance remains unavailable. |
| Full film XOR / all pad geometry | NOT RUN | Primary-reported percentages and 172-pad geometry agreement were not independently reproduced here. |

Machine-readable results: [viewer summary](s2/summary.json), [complete analysis](s2/analysis.json), [connectivity comparison](s2/connectivity.json), [rule summary](s2/rule_summary.json), [hole comparison](s2/drill_comparison.json).

## New finding S2-01: native parity is not clean

Running DRC with `--schematic-parity` adds these **139 warning-level findings** to the separate 67 PCB warnings:

| Count | Difference | Interpretation at this revision |
| --- | --- | --- |
| 34 | Footprint value differs from symbol value | Example: footprint C12 value is `C12`, schematic value is `.1uf`. Board BOM-facing metadata needs synchronization. |
| 67 | Hierarchical net-name prefix | Example: board `SW_NODE`, schematic `/PowerSupply/SW_NODE`. Names differ although associated pin sets agree exactly. |
| 37 | PCB unassigned pad vs schematic generated unconnected name | Each source NC pin is independently isolated in both representations; native naming still differs. |
| 1 | PCB `VBAT` vs schematic `unconnected-(U3-VBAT-Pad1)` | Same single pin U3.1; no extra electrical connection was found. |

All 139 entries fit these categories; there are no unclassified parity findings. See [raw DRC with parity](s2/drc.json). These observations support the primary's narrower pin-set check, but that check is insufficient evidence for a clean, no-change **Update PCB from Schematic** workflow. The CLI returned exit code 0 because `--exit-code-violations` was not requested; the report contents, rather than the exit code, determine this verdict.

**Smallest follow-up for the implementation owner:** in a separately owned working copy of the intended maintained revision, align PCB values and exact schematic net identities, then repeat native parity and inspect the Update-PCB change list before applying it. Preserve source connectivity and copper geometry throughout. Do not silently waive these findings because the pin-set check passes. This reviewer made no implementation edits.

## DRC and ERC interpretation

The 67 PCB warnings reproduce the primary handoff exactly: 37 solder-mask bridges, 21 silk-over-copper, 6 silk-edge clearance issues and 3 isolated copper islands. [ERC](s2/erc.json) independently reproduces zero violations.

Zero DRC errors is conditional on the released `.kicad_pro` and `.kicad_dru`, both included in the hashed snapshot. The custom rules model the preserved artwork, including minimum 5 mil pour clearance, 7.5 mil track-to-track, 9.5 mil track-to-via and 3.3 mil track-to-pad clearance. This verifies that specific rule configuration; it is not evidence that a redesign meets a different fabricator's requirements. ERC and DRC also do not validate regulator/MCU application requirements, actuator behavior or firmware safety.

## Independent comparison method

The review parser reads `pstxnet.dat` directly and checks full parsed node coverage. Schematic connectivity comes from KiCad's XML netlist export; PCB pads come from `pcbnew.LoadBoard`. References are resolved using the saved `Allegro_RefDes` properties, rather than deleting an assumed trailing digit. The PCB property reader consumes top-level footprint property blocks from the same hashed PCB because KiCad 9's Python footprint API does not expose the older `GetProperty` method.

The comparison includes **all 172 pins**, including every NC and VBAT pin. The source's NC list is split into 37 independent single-pin groups, because it denotes unconnected pins rather than a shared electrical net. Thus the source, schematic and PCB each produce the same **69 pin groups**: 31 multi-pin nets, one singleton VBAT net and 37 isolated pins. Duplicate memberships and missing/extra references, paths and library IDs are checked separately. This establishes declared connectivity; the separate DRC checks routed connectivity under the saved rules.

The hole check independently parses absolute RS-274X flash commands from the V5 `BOATCREWTOPL.art` and `BOATCREWBOTL.art`, retaining round flashes in dark polarity. Both yield the same 53 centers. After inverting Gerber Y, the independently solved common translation is +100 mm X and +100 mm Y. Bidirectional nearest-center comparison matches every board hole within 0.05 mil; measured maximum is approximately `7.9e-13` mil, i.e. numerical roundoff. No source drill diameter is inferred from a copper annulus. The supplied drill's identity with V4 was independently rechecked after removing only the `;FILE` line.

## Reproduction and provenance

Run from the repository root in PowerShell. Tool versions: KiCad **9.0.7**, bundled Python **3.11.5**. All output stays under `reviews/codex/s2/`.

```powershell
& 'C:\Users\Jay\AppData\Local\Programs\KiCad\9.0\bin\python.exe' reviews/codex/s2/verify.py
& 'C:\Users\Jay\AppData\Local\Programs\KiCad\9.0\bin\python.exe' reviews/codex/s2/analyze.py
```

`verify.py` uses `git rev-parse`, `git ls-tree` and `git show` to export the selected commit, then runs these exact CLI operations against the snapshot:

```powershell
& 'C:\Users\Jay\AppData\Local\Programs\KiCad\9.0\bin\kicad-cli.exe' sch export netlist --format kicadxml --output reviews/codex/s2/netlist.xml reviews/codex/s2/snapshot/hardware/kicad/LoRa_Boat_Controller.kicad_sch
& 'C:\Users\Jay\AppData\Local\Programs\KiCad\9.0\bin\kicad-cli.exe' sch erc --severity-all --format json --output reviews/codex/s2/erc.json reviews/codex/s2/snapshot/hardware/kicad/LoRa_Boat_Controller.kicad_sch
& 'C:\Users\Jay\AppData\Local\Programs\KiCad\9.0\bin\kicad-cli.exe' pcb drc --severity-all --schematic-parity --format json --output reviews/codex/s2/drc.json reviews/codex/s2/snapshot/hardware/kicad/LoRa_Boat_Controller.kicad_pcb
```

The actual full-path arguments, stdout and exit codes are in [commands.json](s2/commands.json). The first inventory attempt encountered a KiCad API difference; a later attempt required an explicit layer for `PCB_VIA.GetWidth`. The inventory was completed with the corrected script using `verify.py --resume-inventory`, without re-running the CAD checks. [run.json](s2/run.json) records the inventory completion/version and snapshot stability. `analyze.py` then completed successfully, including the additional duplicate/count checks. Neither script imports the primary converter.

Complete input hashes are in [input_manifest.json](s2/input_manifest.json), including every sheet, library, project rule and compared source file. Key SHA-256 hashes:

| Input | SHA-256 |
| --- | --- |
| PCB | `ec6bed5c721ed33bb8c6b88f40d2e60b12b2a180a92e1e845dd7ffb373587597` |
| Root schematic | `8af5beedd78649b91e4ae29dd99a0e7721ae9e9617cc53daf528e3db2f8df8ae` |
| V5 pstxnet.dat | `b88c36244bb3e3eb4d10712ce8ca39ddb5908e2c3225aa187155f9f4dca6b02c` |
| Custom rules | `7d5337c38b2be25b88bbe9782c88fd56e48c7ec7e023646d69ff9805f43dc82c` |

## Limits and handoff

Unperformed in this bounded packet: full copper/mask/silk/outline XOR, all-pad geometric matching, visual schematic review, Update-PCB GUI exercise, firmware compilation, physical measurements and powered-hardware tests. Independent hole-center agreement does not prove finished-hole diameter or plating. No result here establishes safe actuator operation or fabrication readiness.

Files changed by this review are confined to this report and `reviews/codex/s2/**`. The implementation owner can use the exact pin-set pass immediately as V1 conversion evidence, while tracking S2-01 and drill provenance as open transfer limitations. The next smallest verification packet should target one explicitly released maintained revision and its native schematic/PCB parity; it should not silently substitute a moving working tree for this hashed V1 baseline.

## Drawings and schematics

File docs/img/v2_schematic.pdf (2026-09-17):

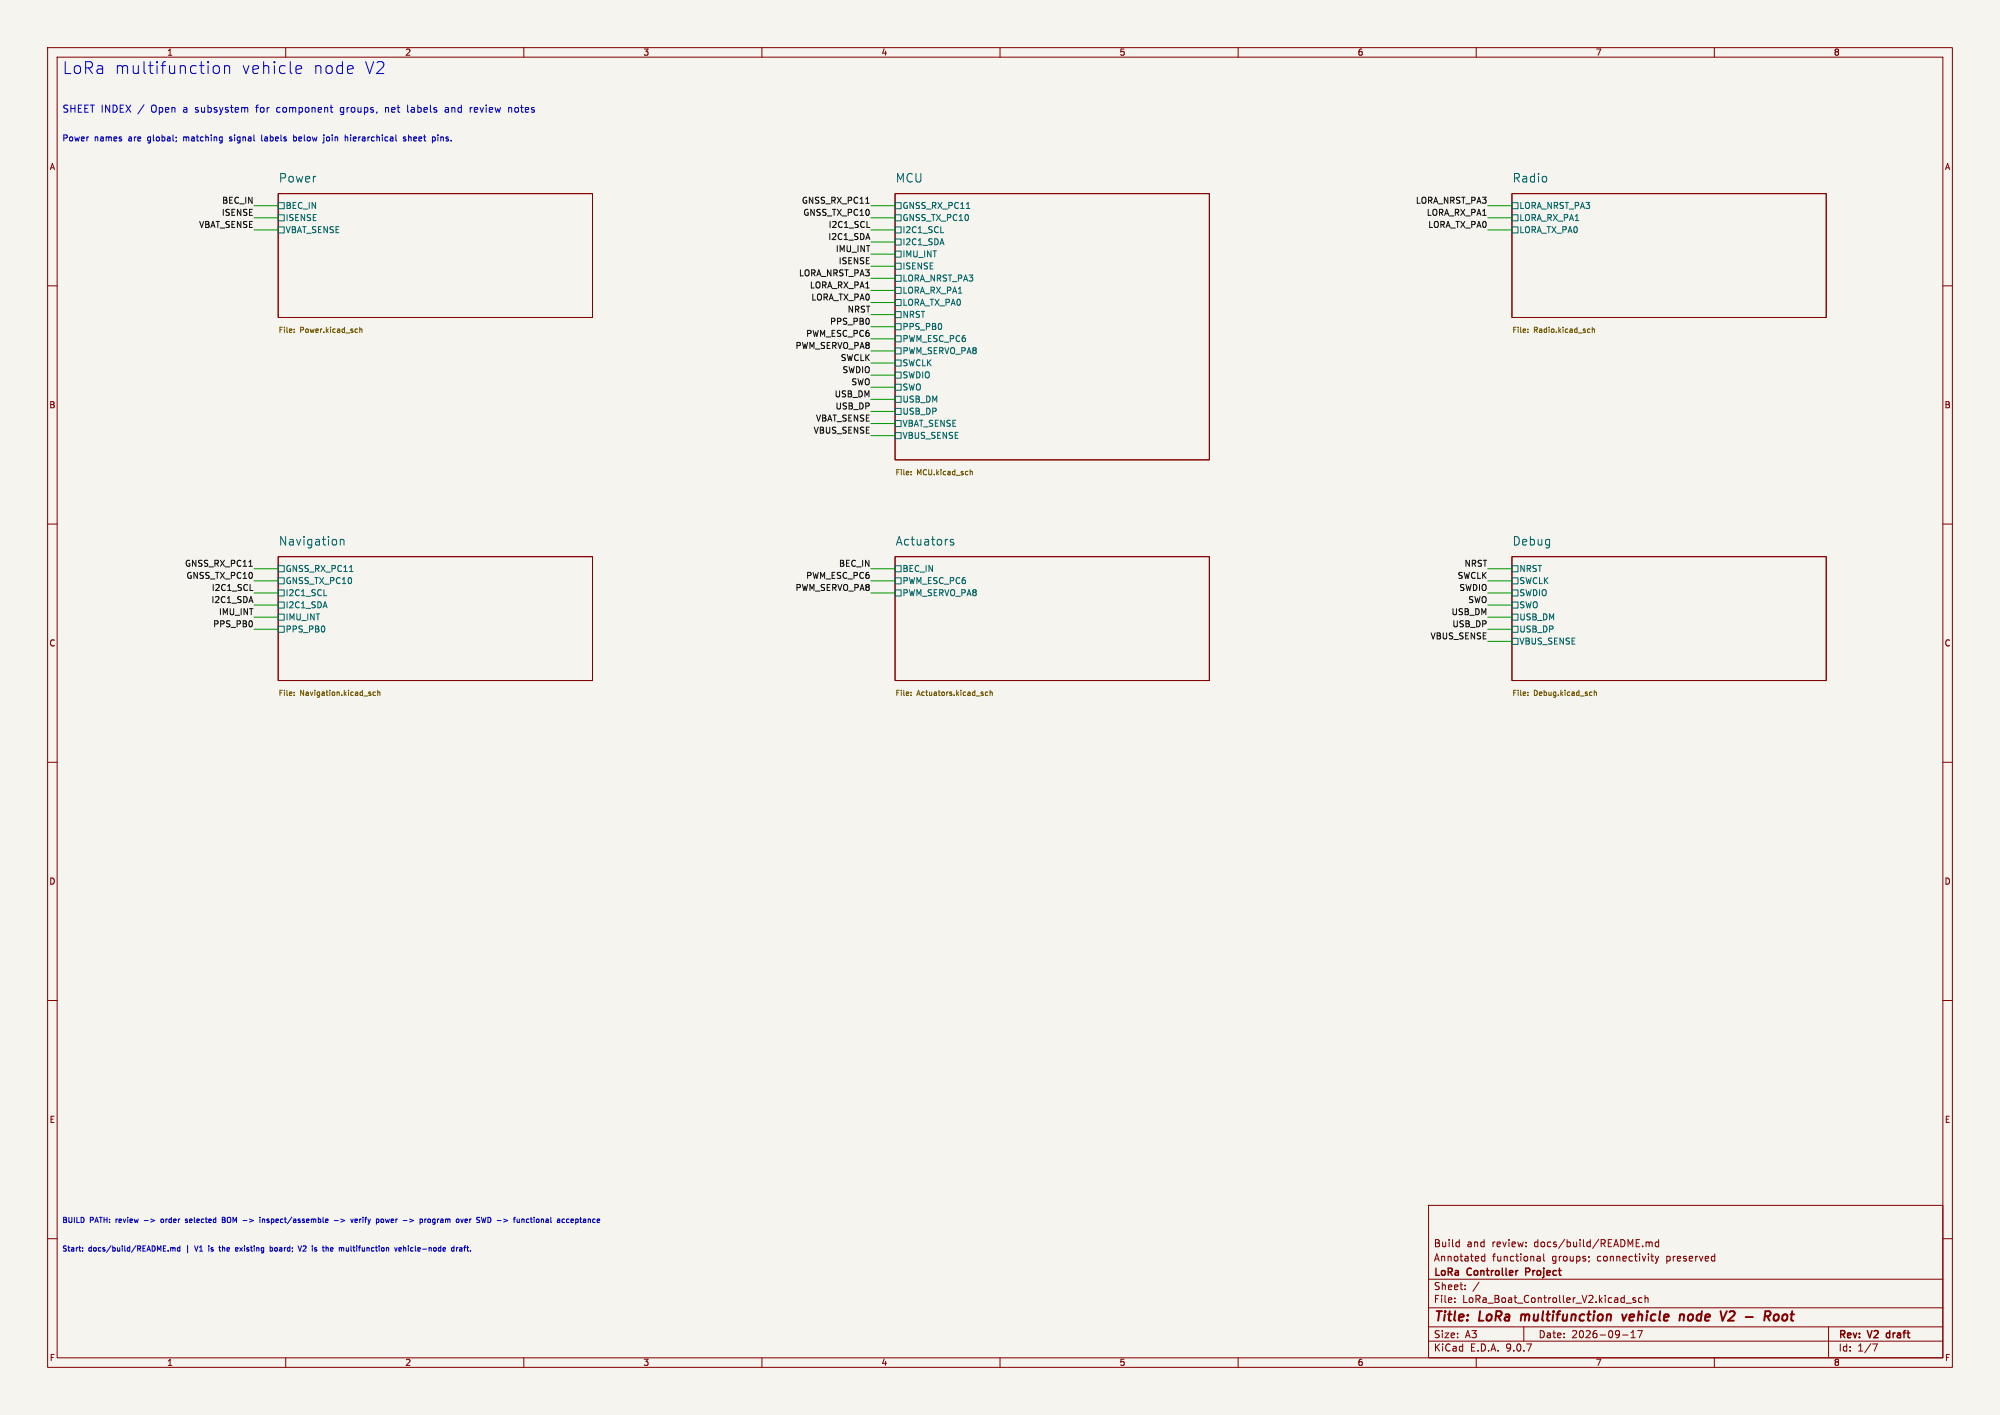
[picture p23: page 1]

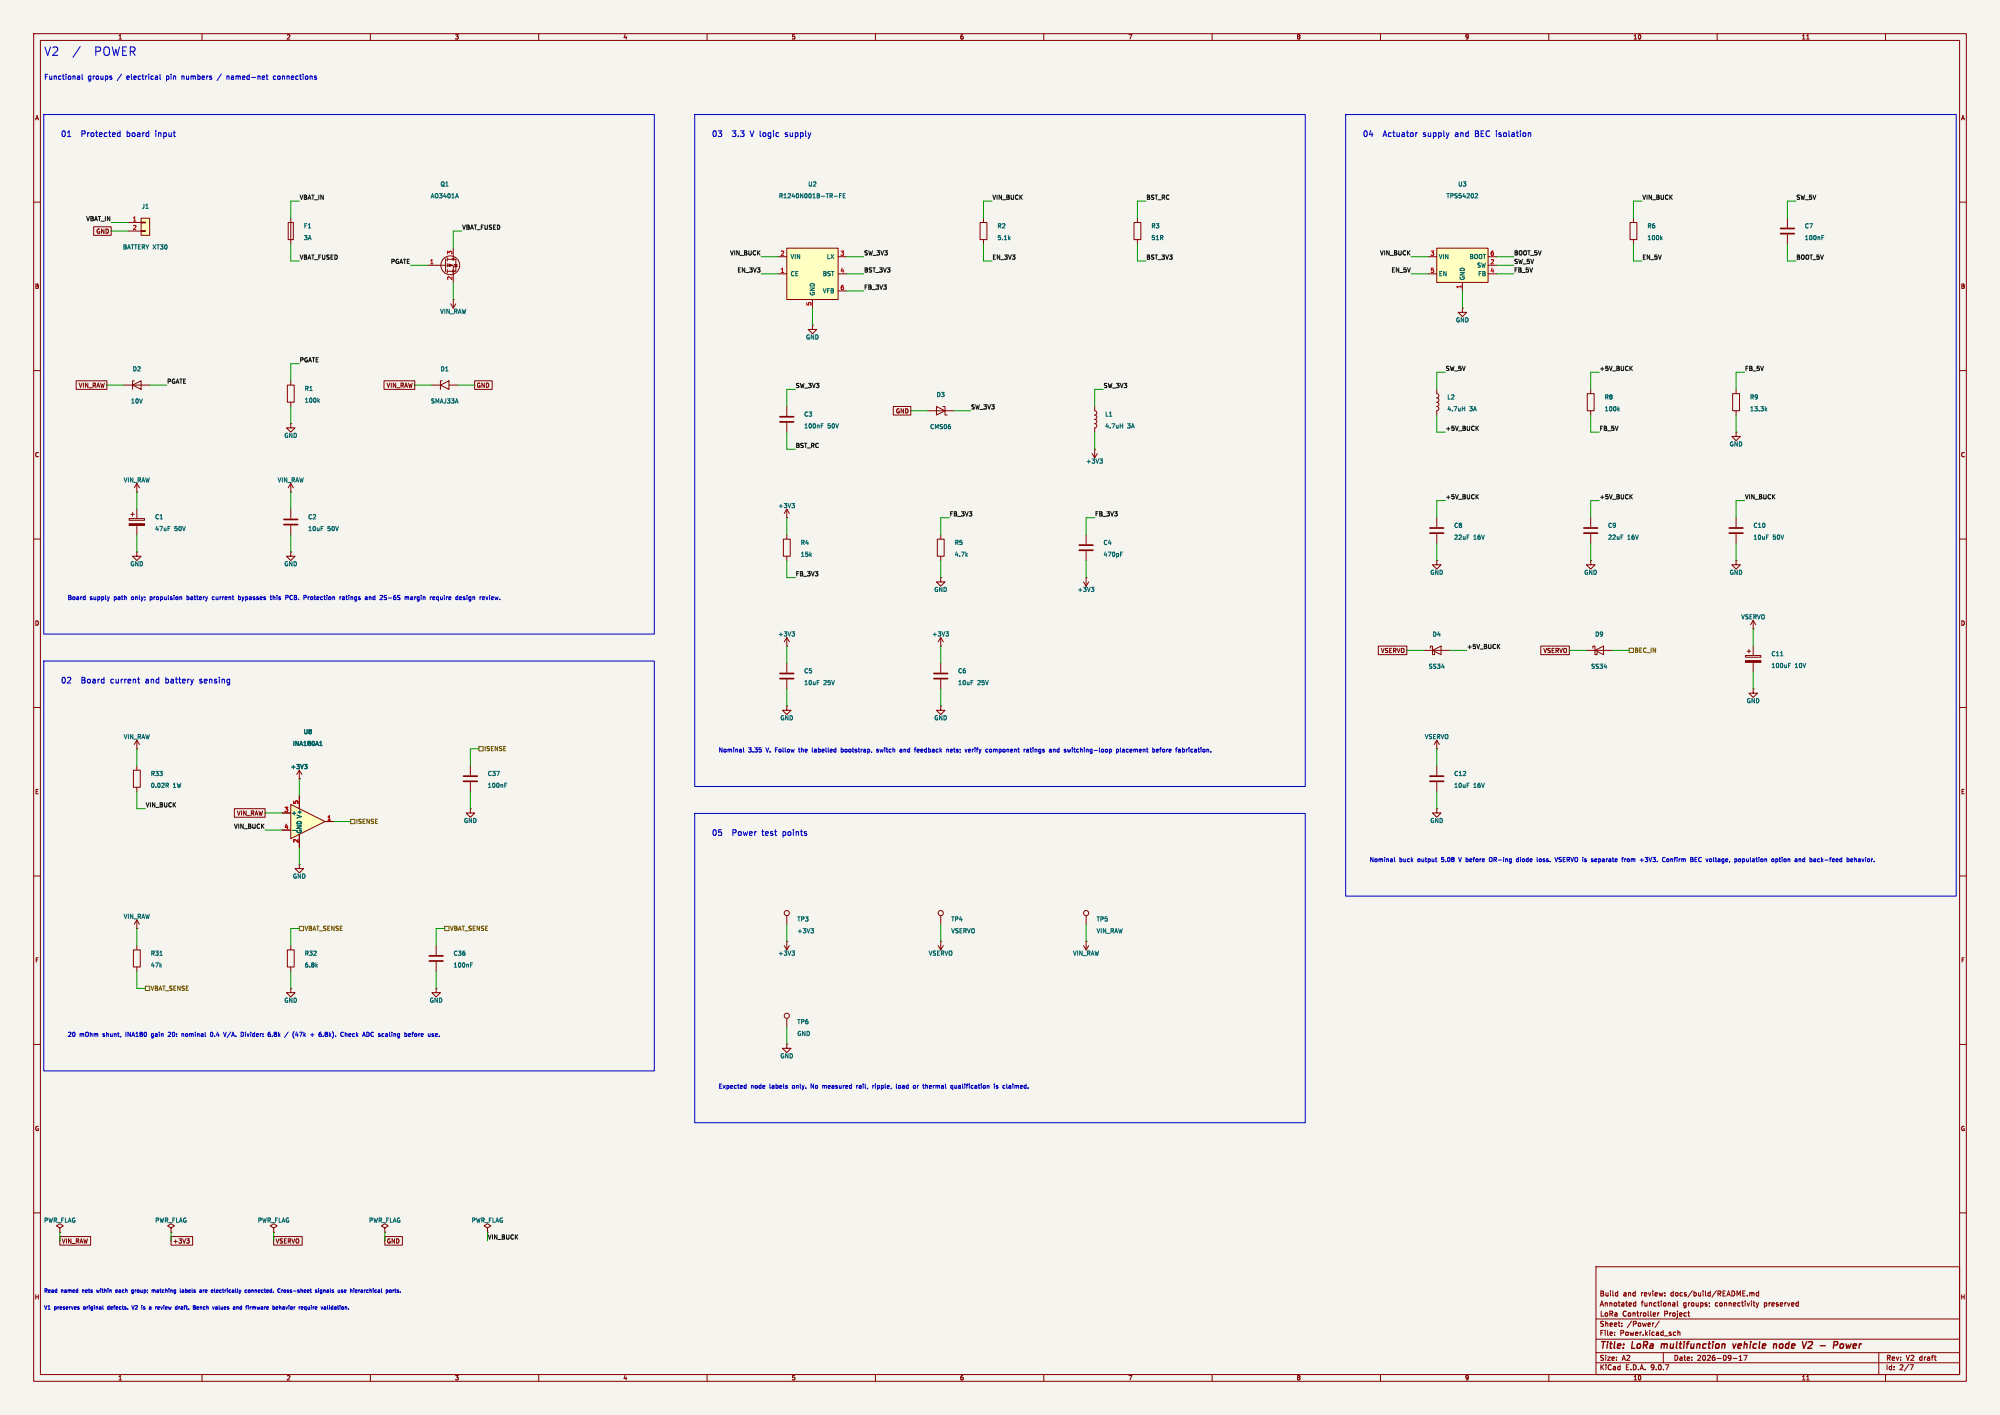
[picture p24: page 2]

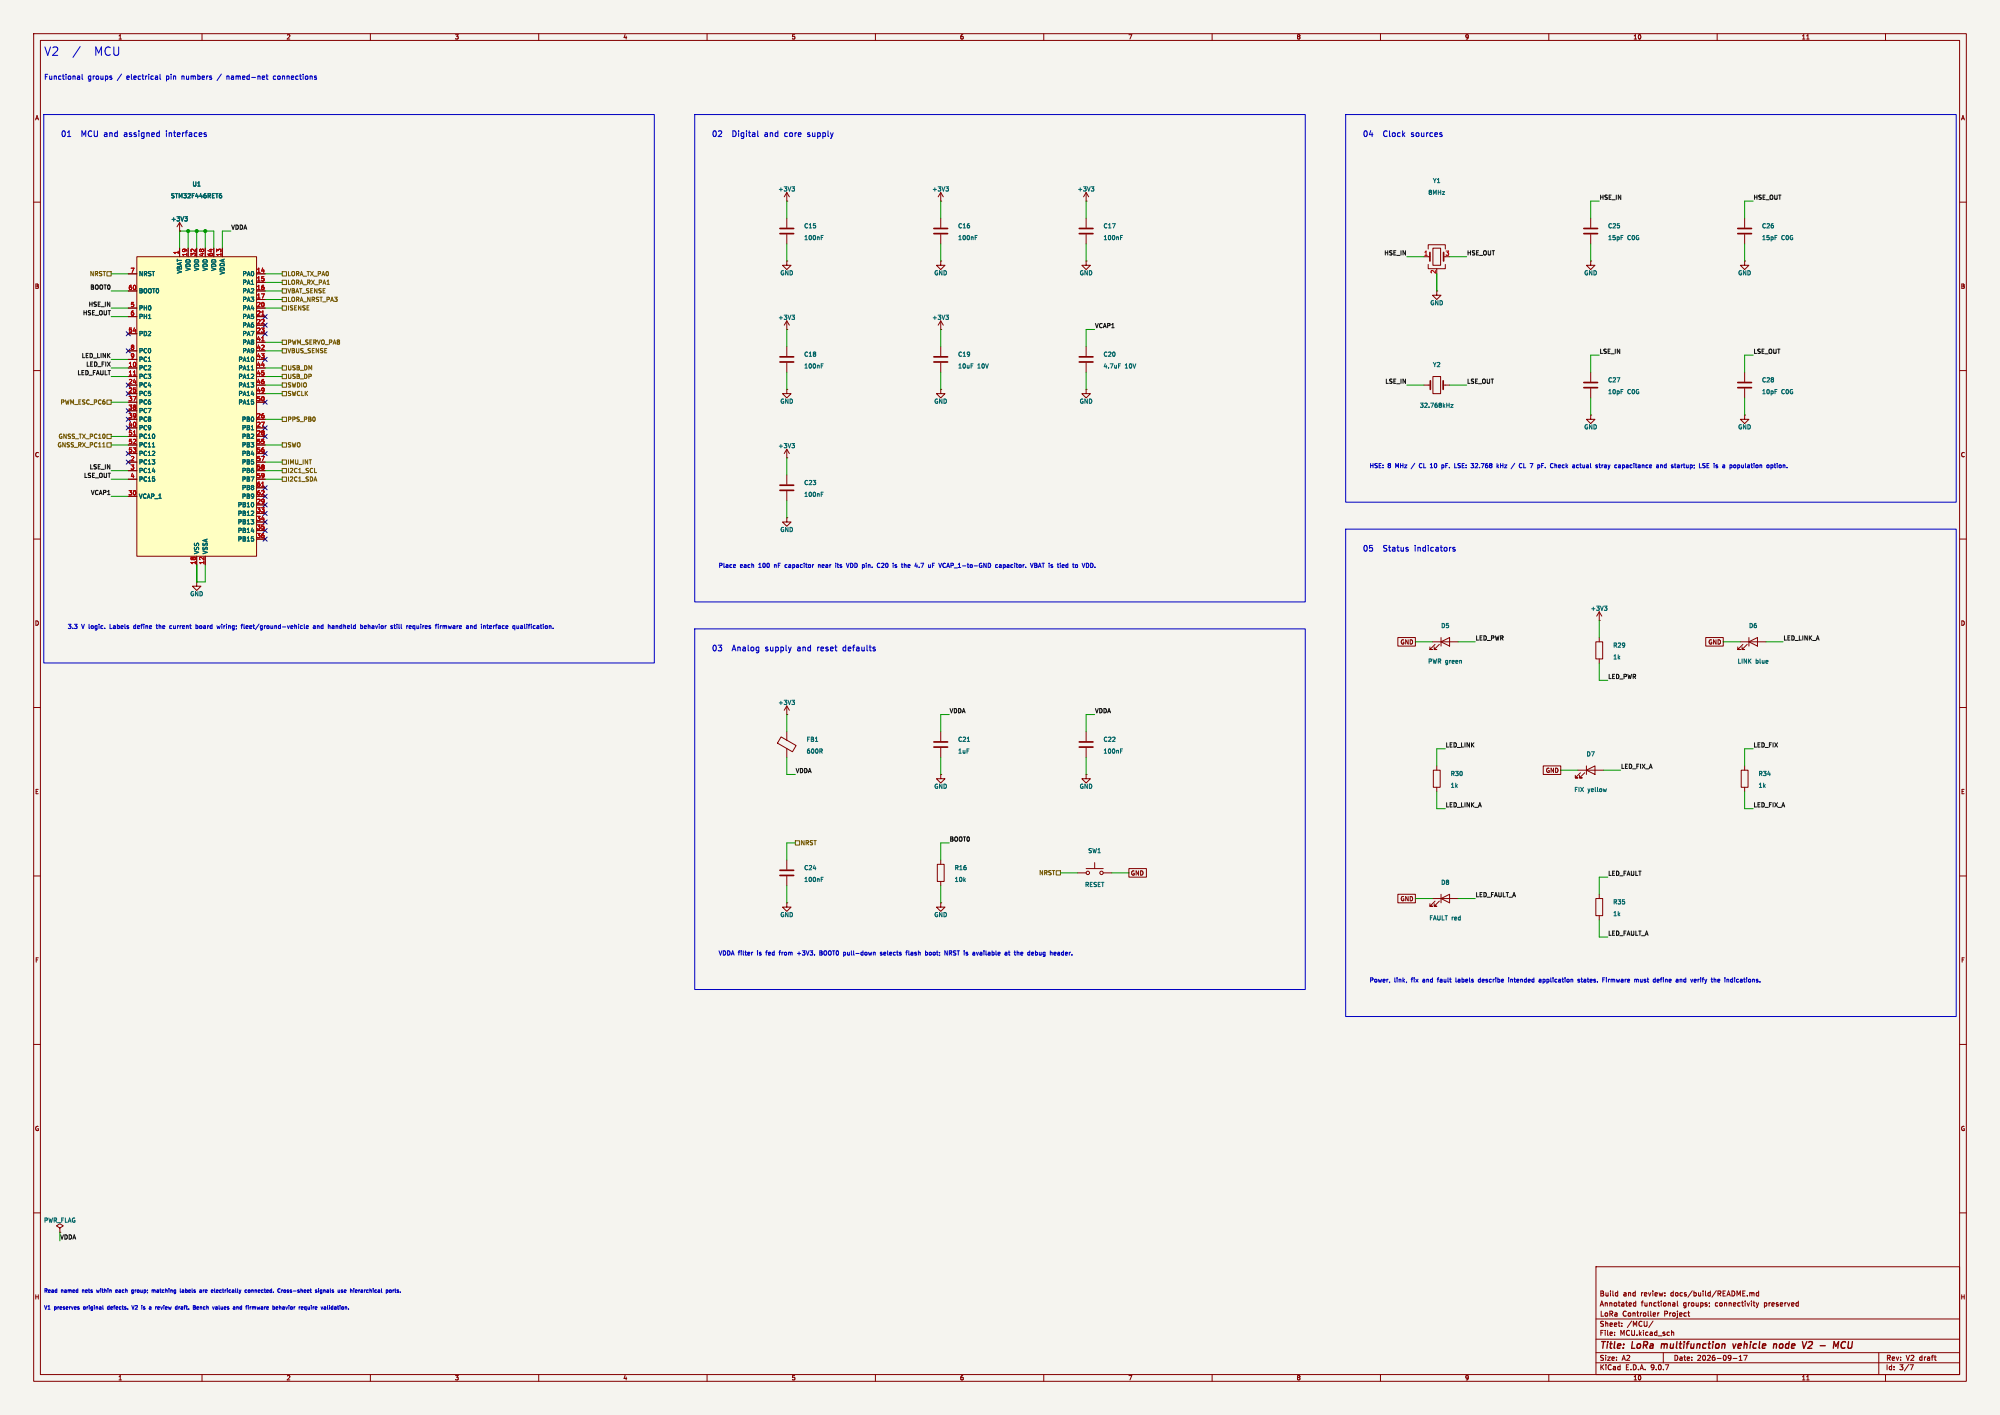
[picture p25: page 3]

1 VDD 19 VDD 32 VSS 18 VDD 48 VSSA 12 VDD 64 VDDA 13 PA0 14 PA1 15 PA2 16 PA3 17 PA4 20 PA5 21 PA6 22 PA7 23 PA8 41 PA9 42 PA10 43 PA11 44 PA12 45 PA13 46 PA14 49 PA15 50 PB0 26 PB1 27 PB2 28 PB3 55 PB4 56 PB5 57 PB6 58 PB7 59 PB8 61 PB9 62 PB10 29 PB12 33 PB13 34 PB14 35 PB15 36

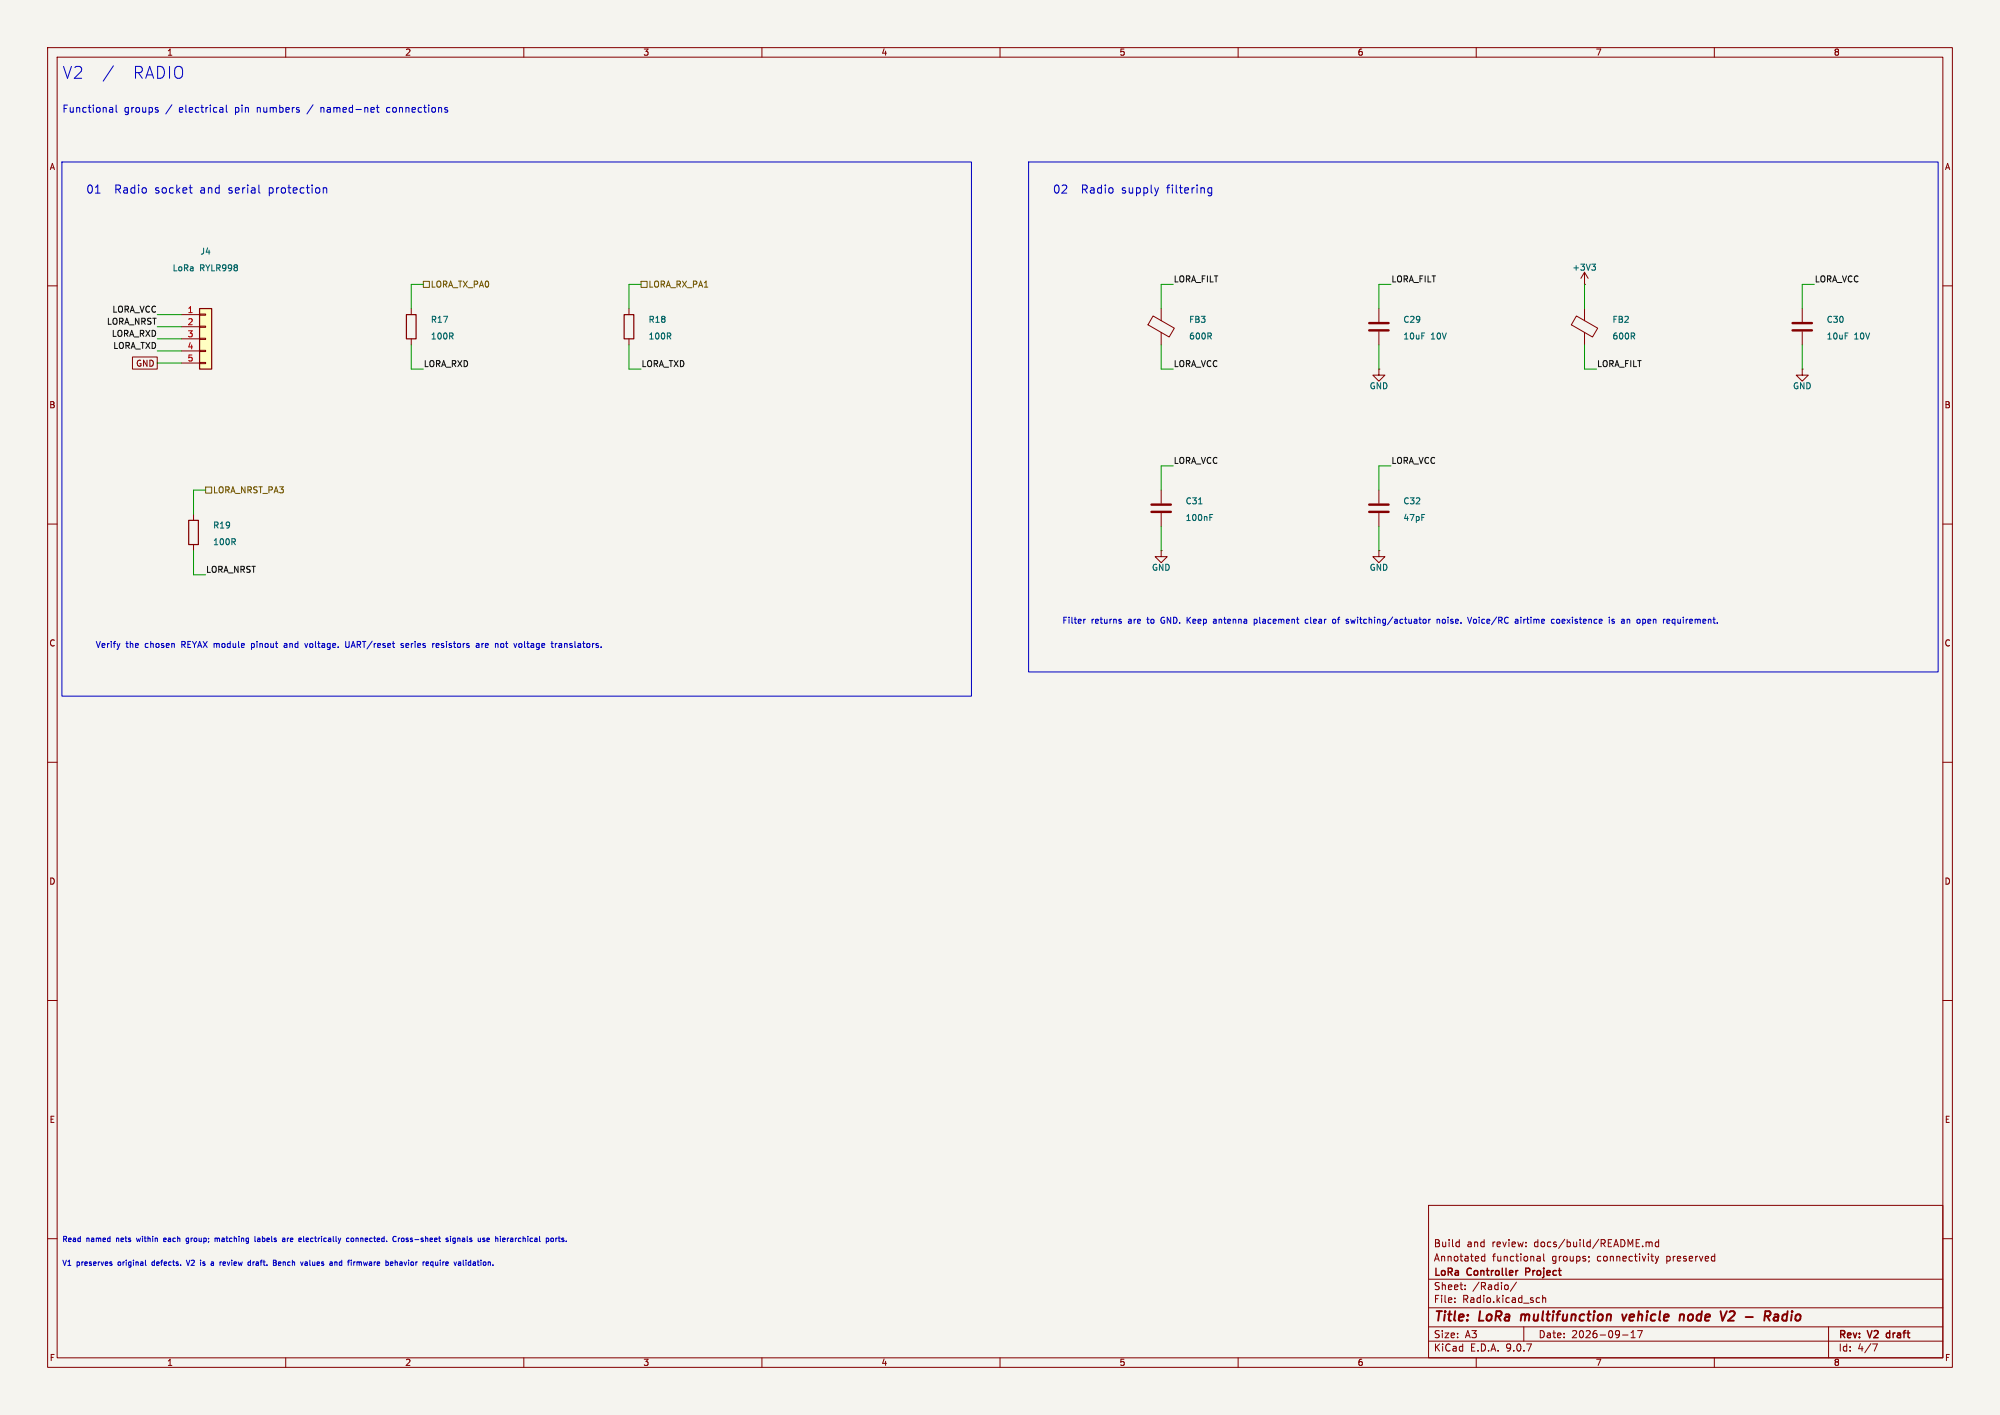
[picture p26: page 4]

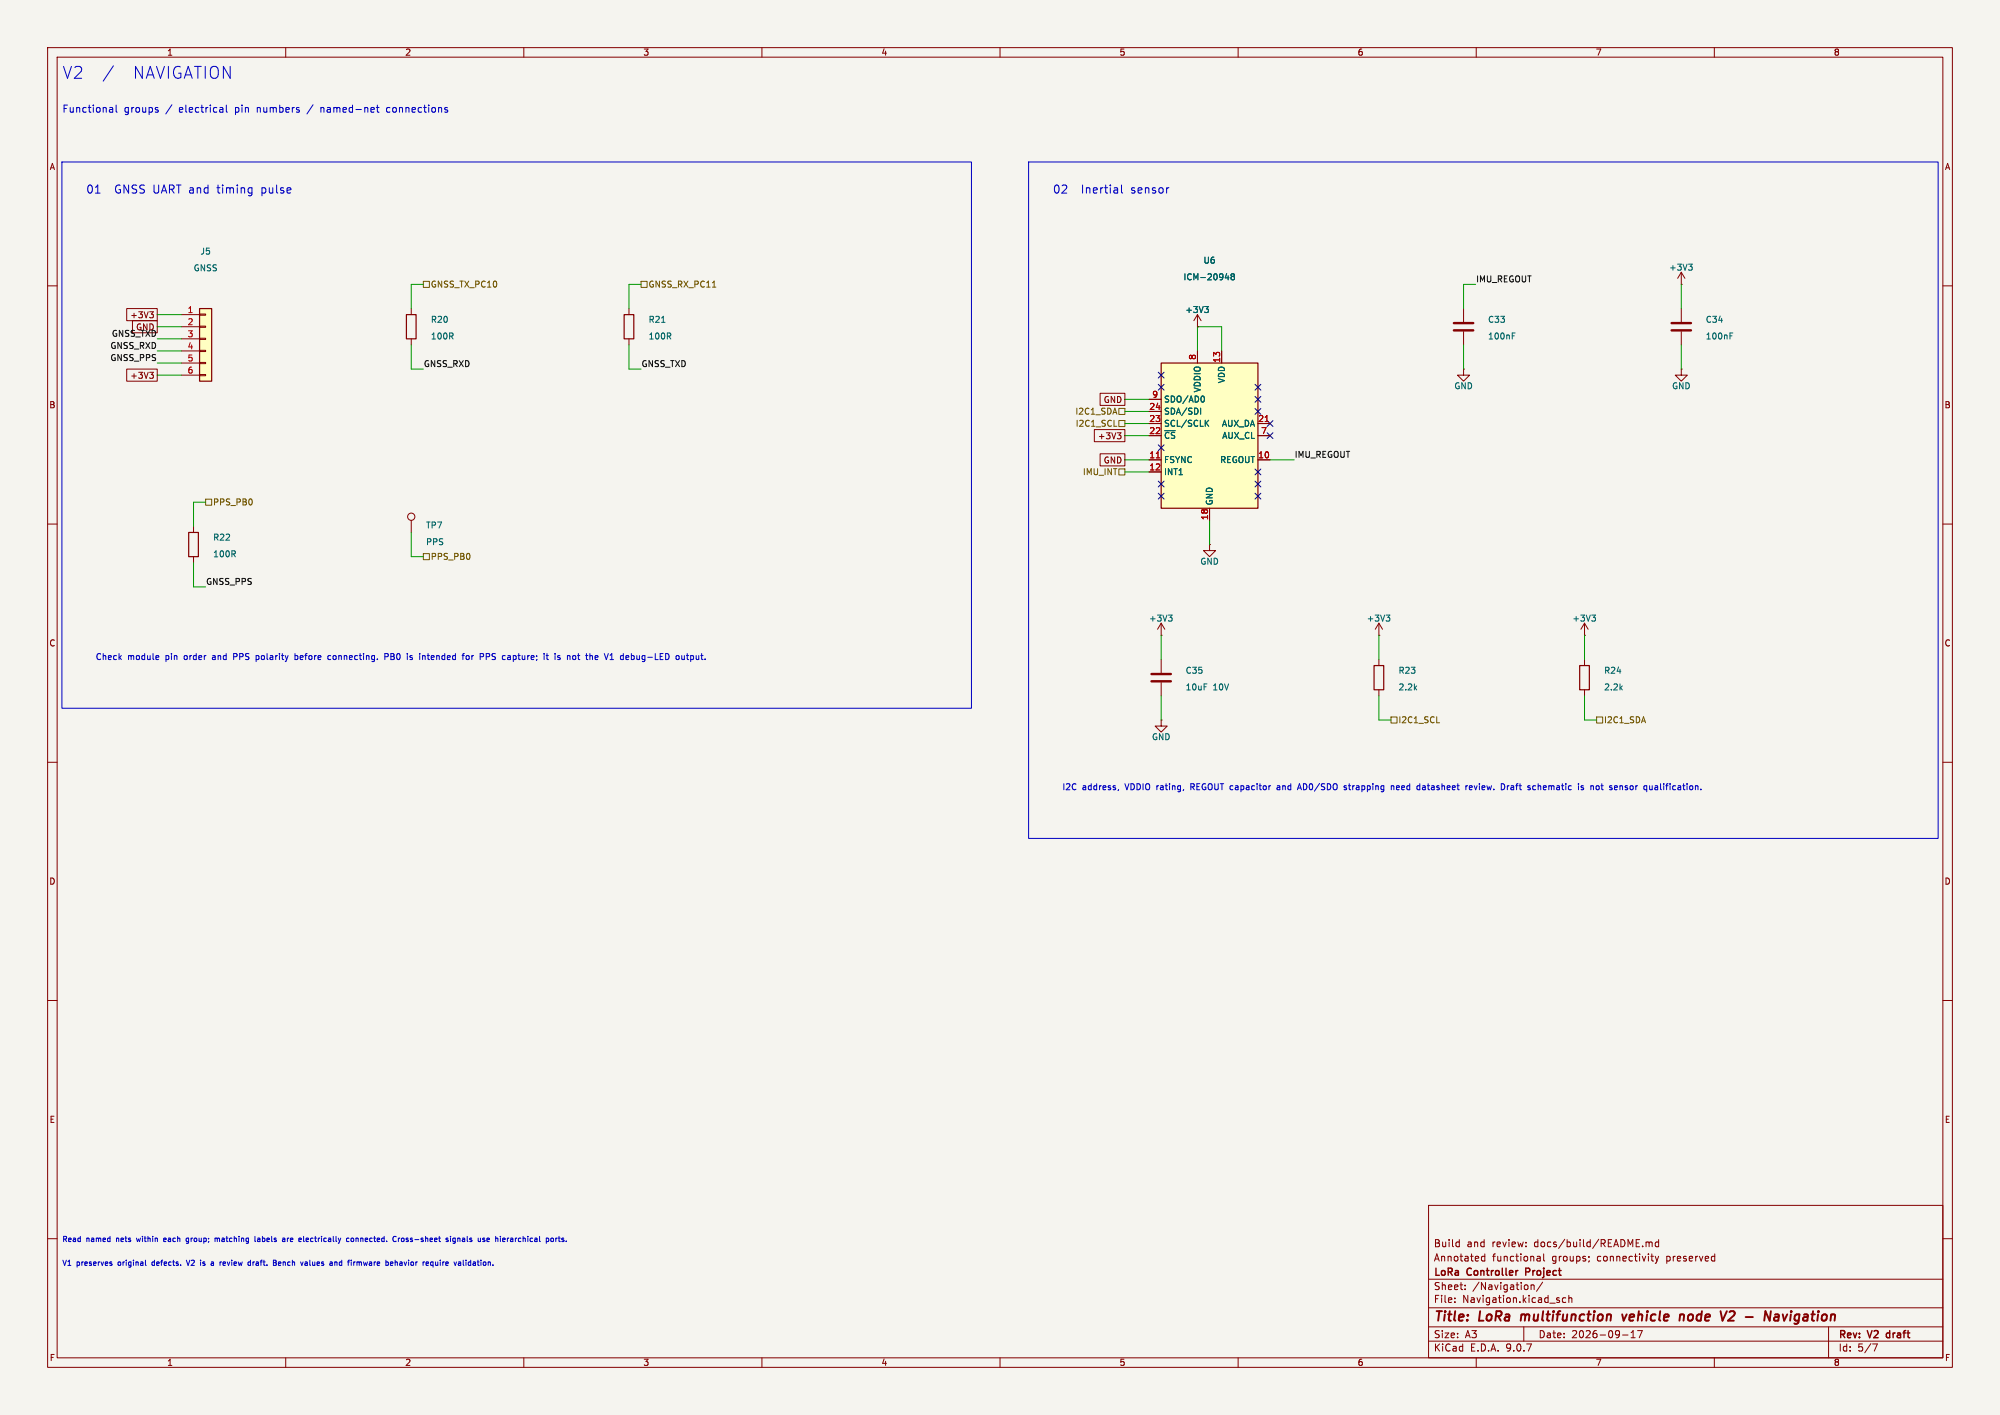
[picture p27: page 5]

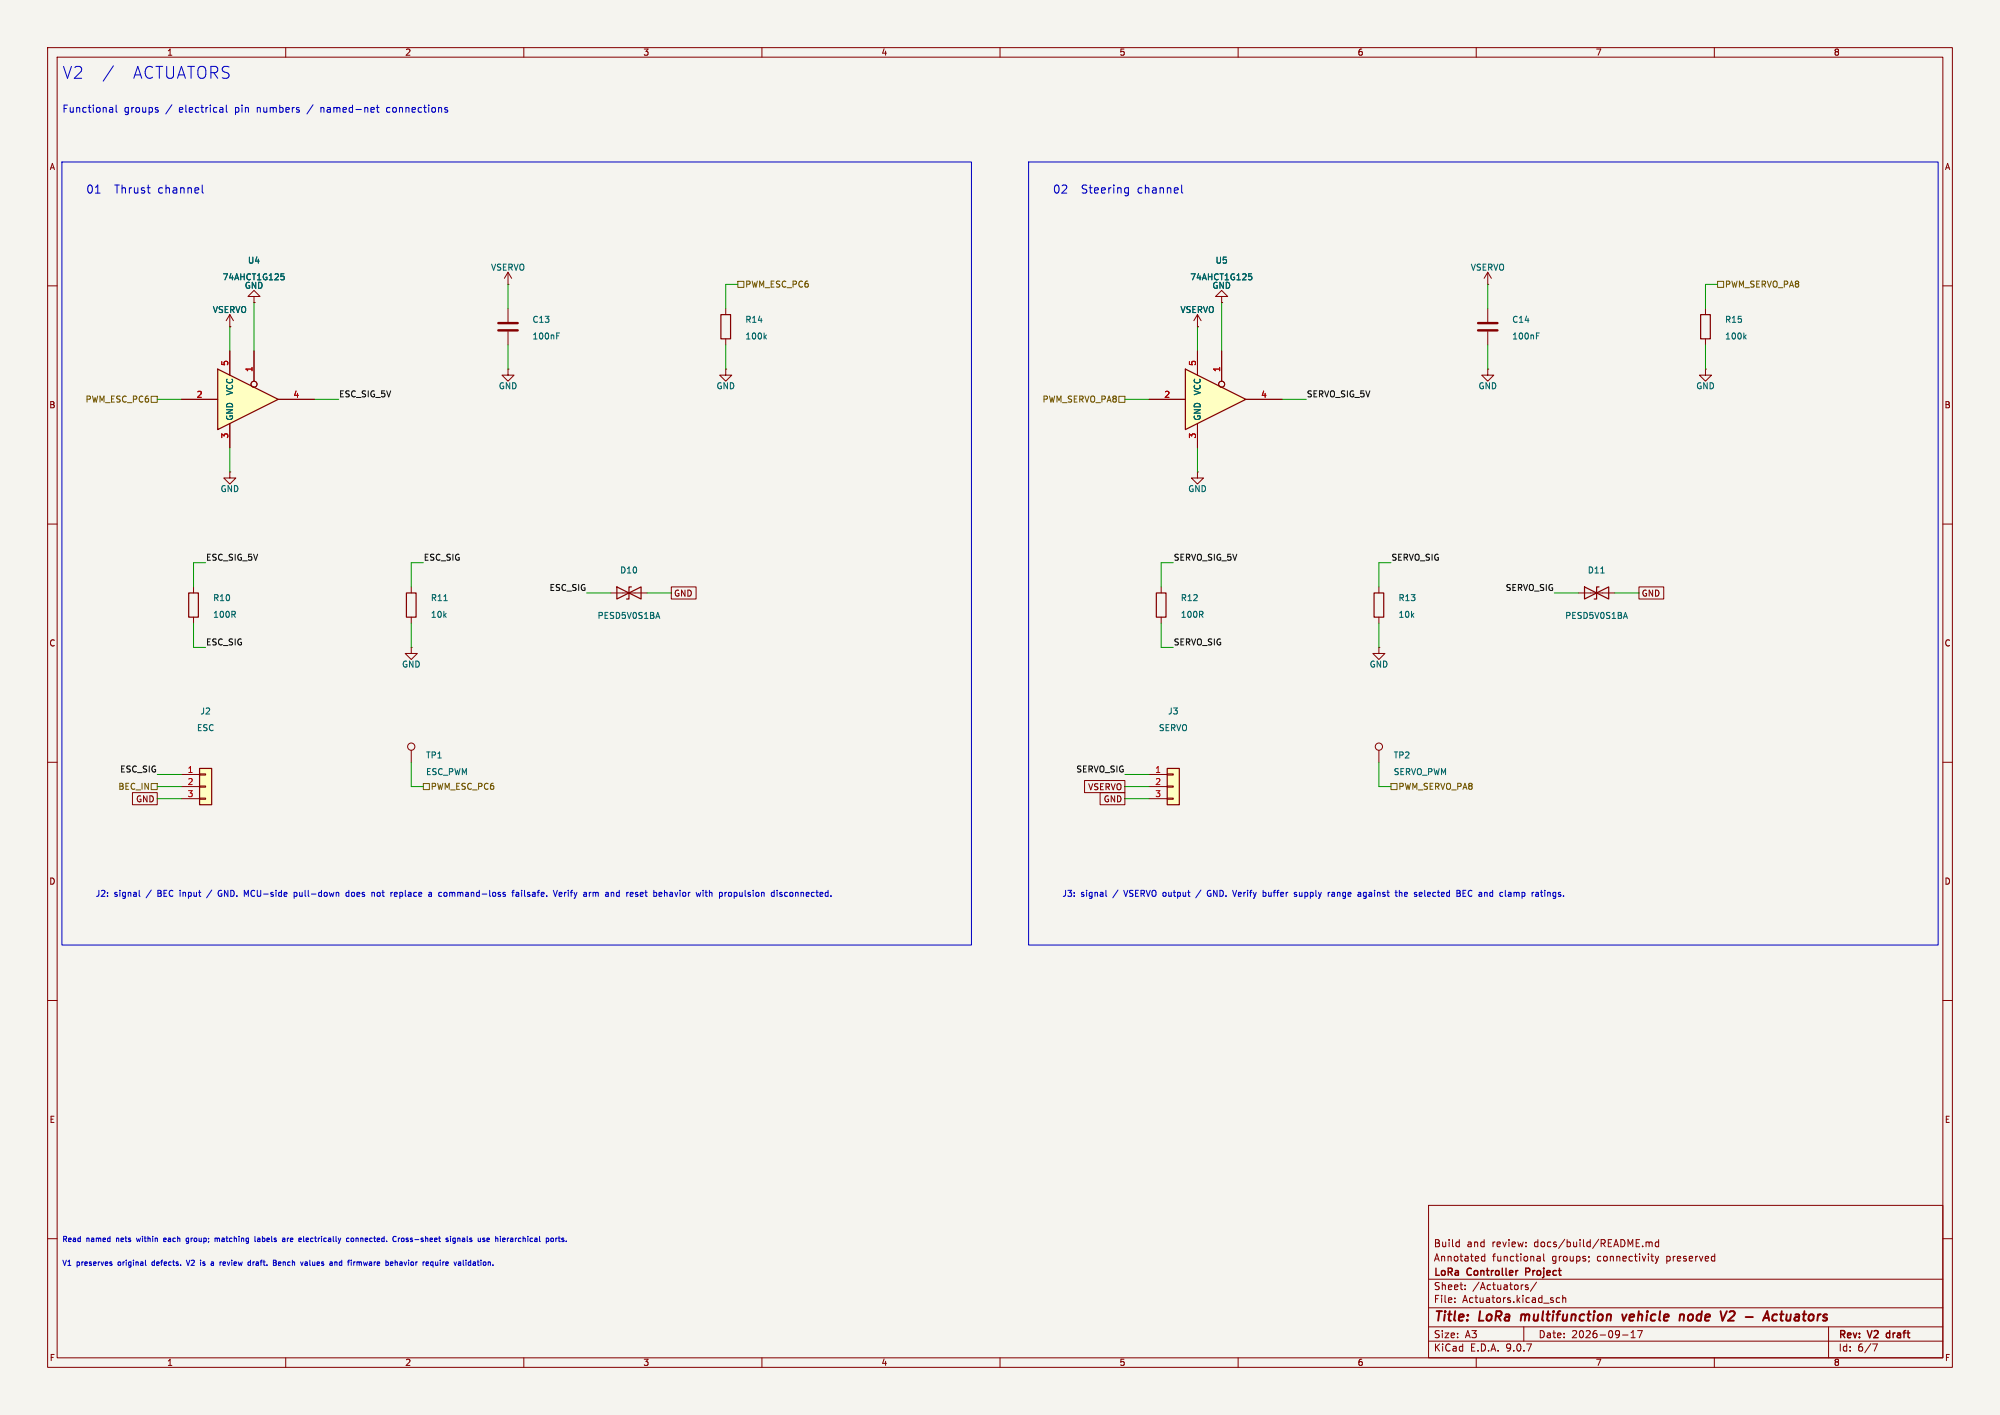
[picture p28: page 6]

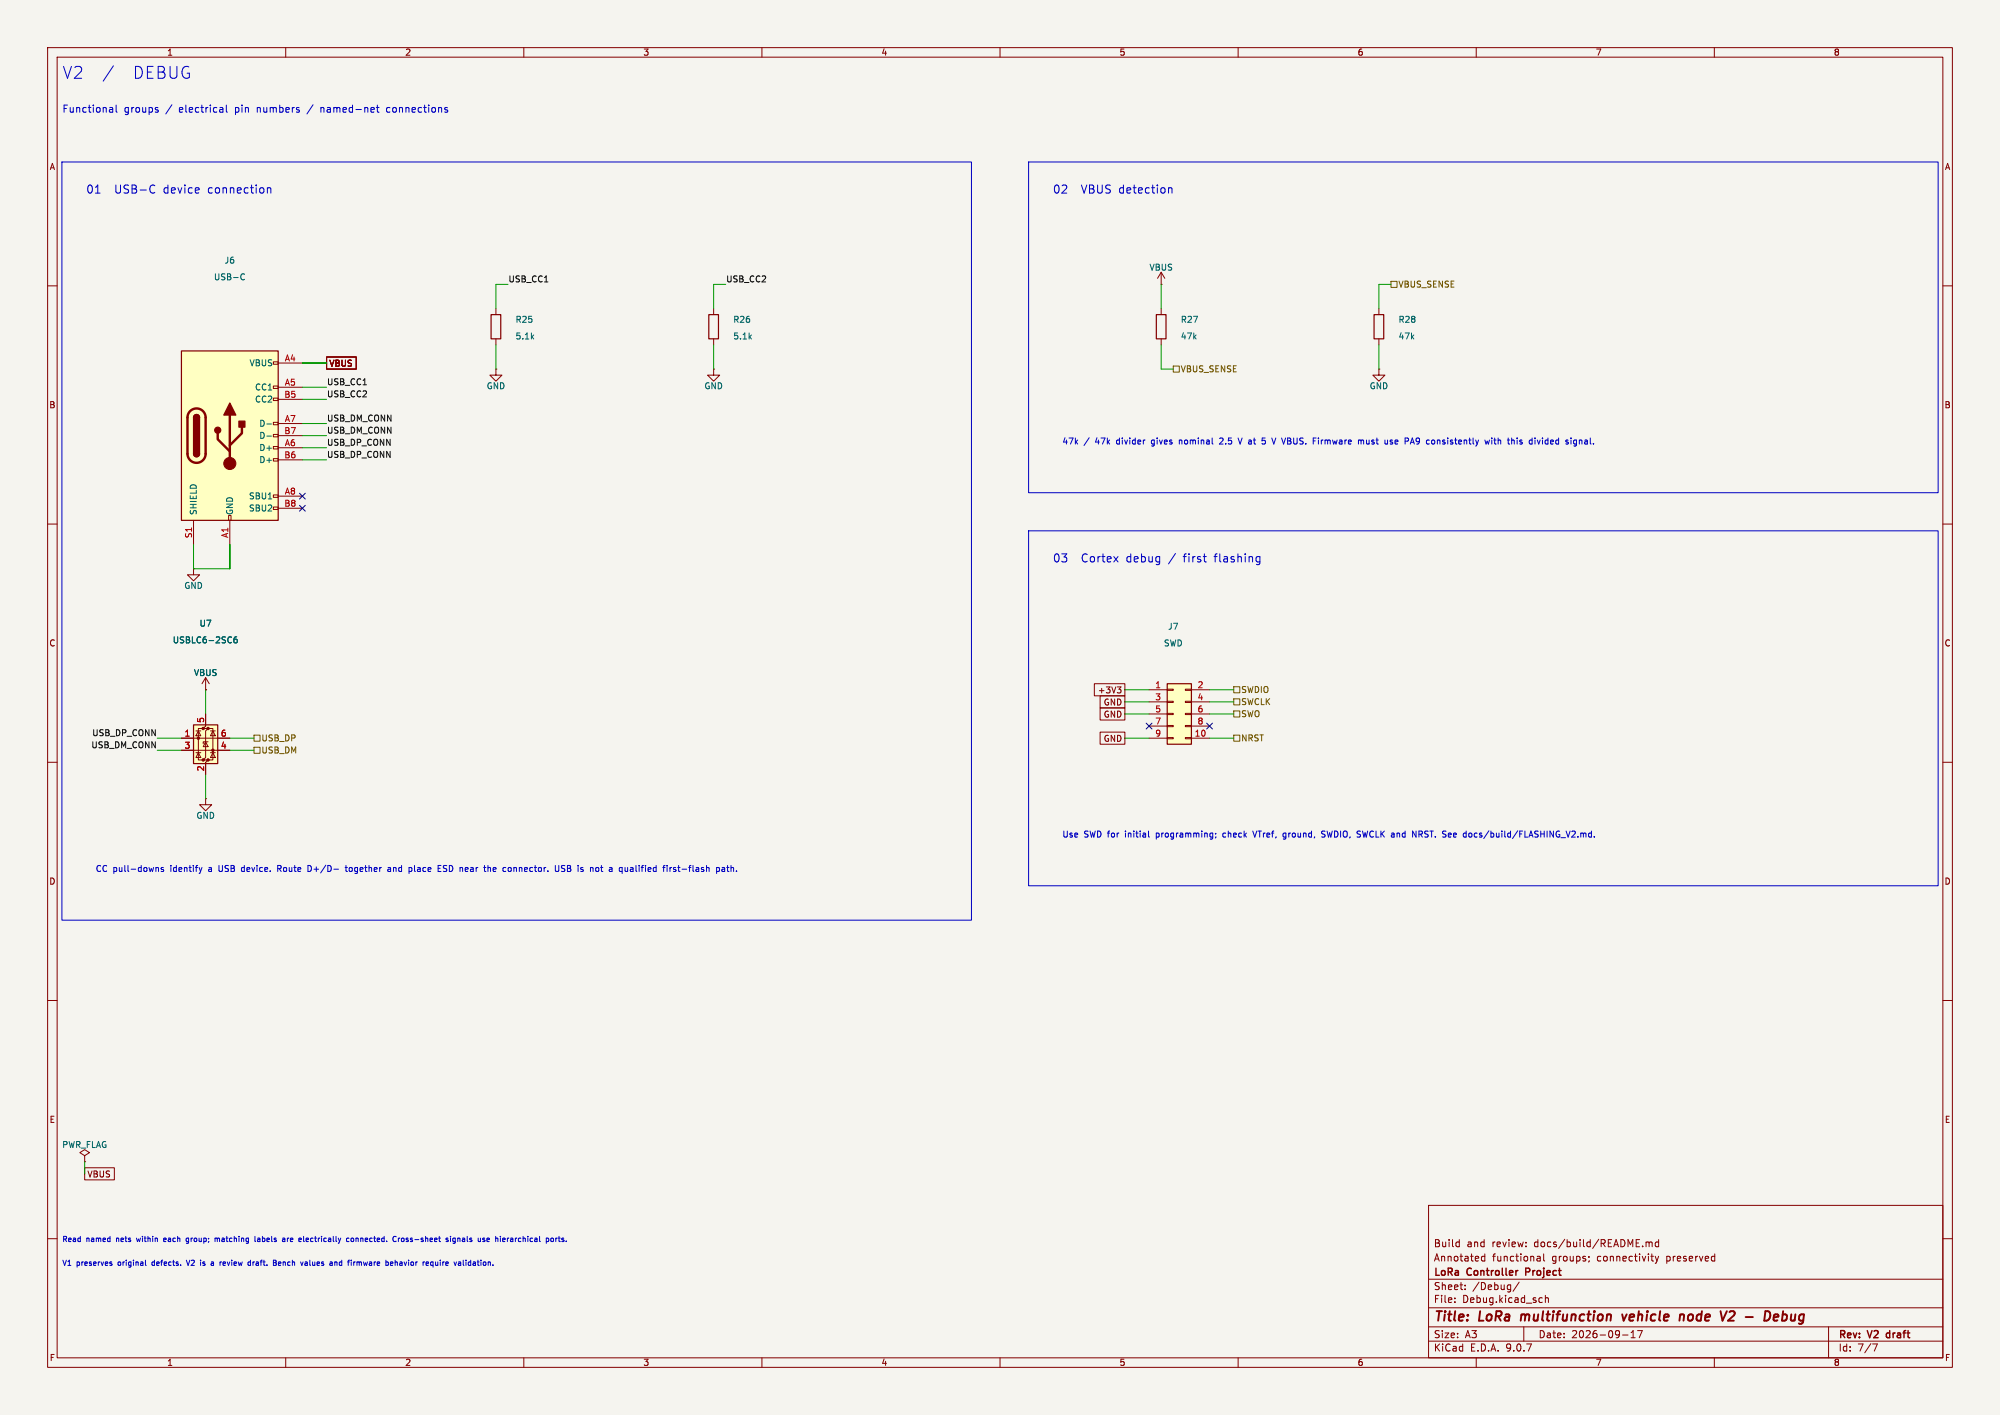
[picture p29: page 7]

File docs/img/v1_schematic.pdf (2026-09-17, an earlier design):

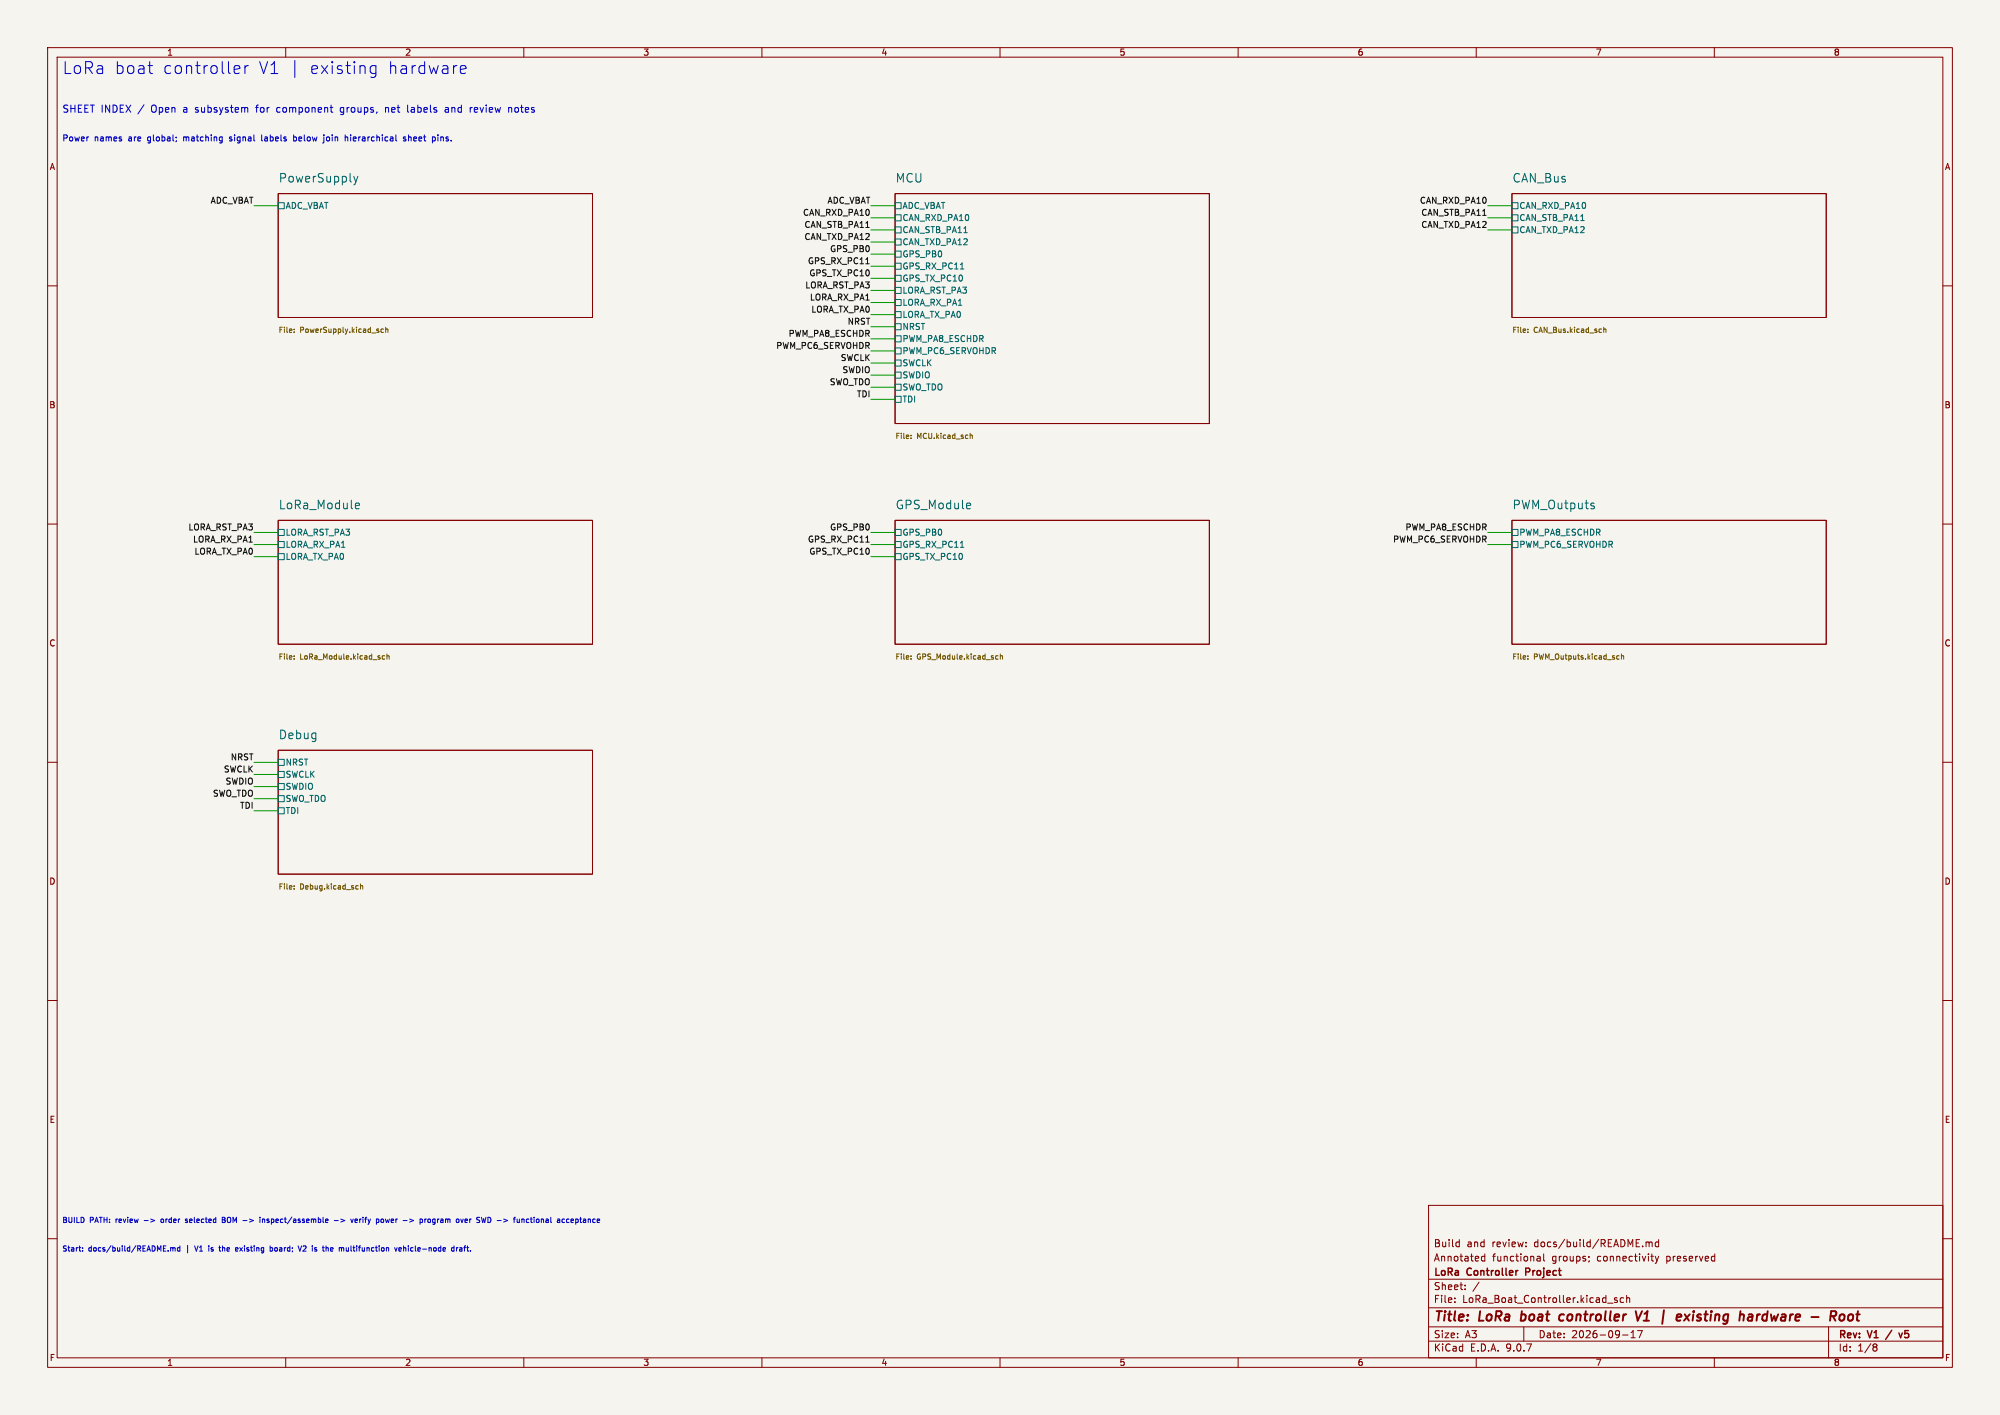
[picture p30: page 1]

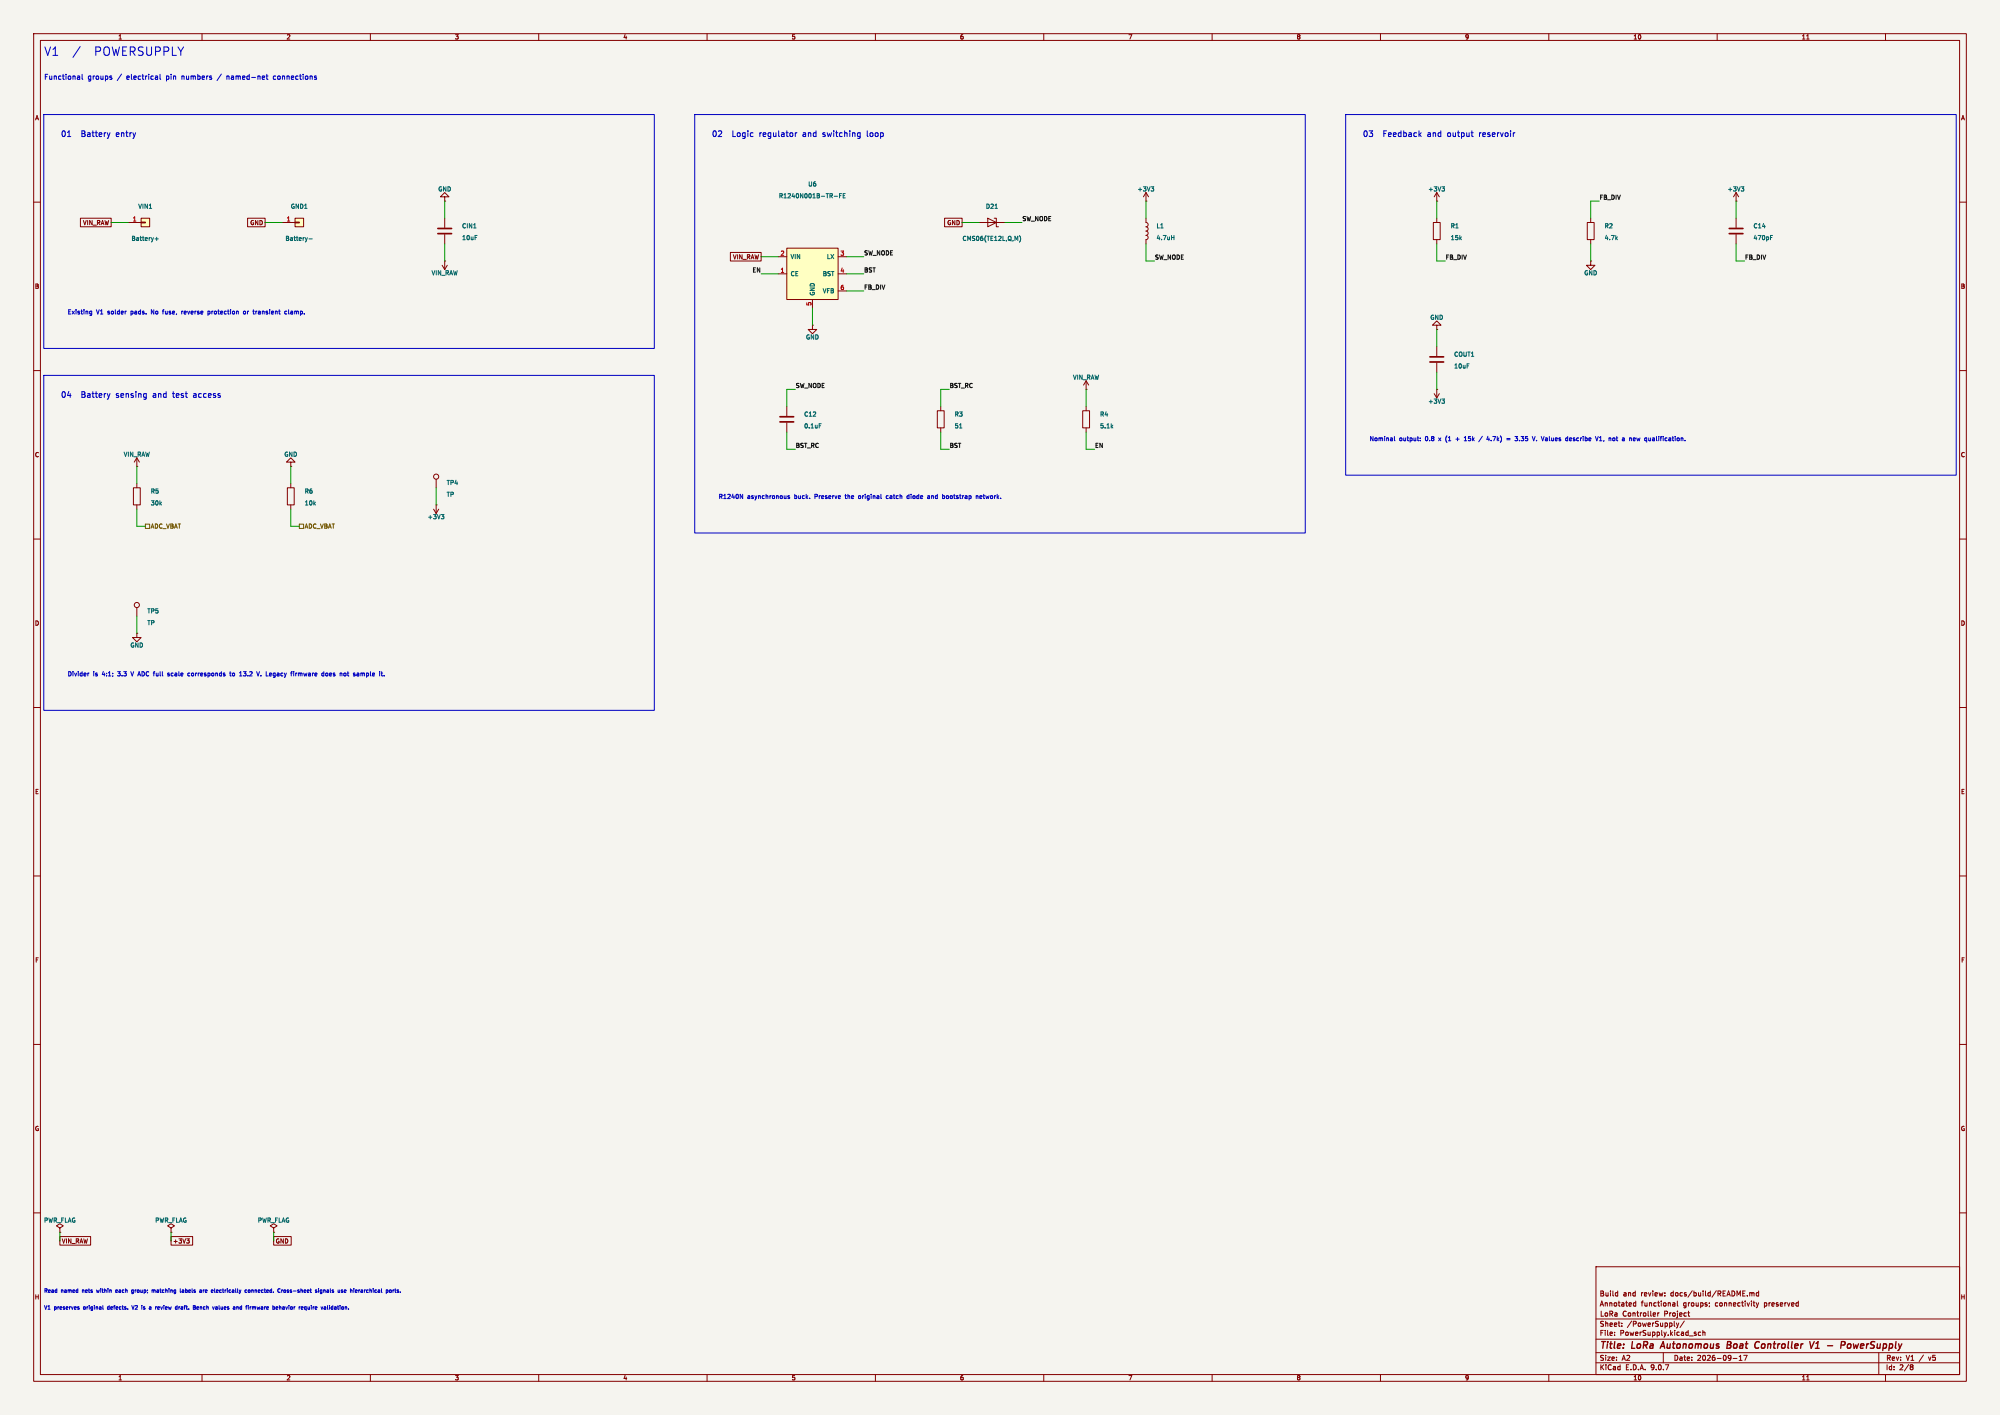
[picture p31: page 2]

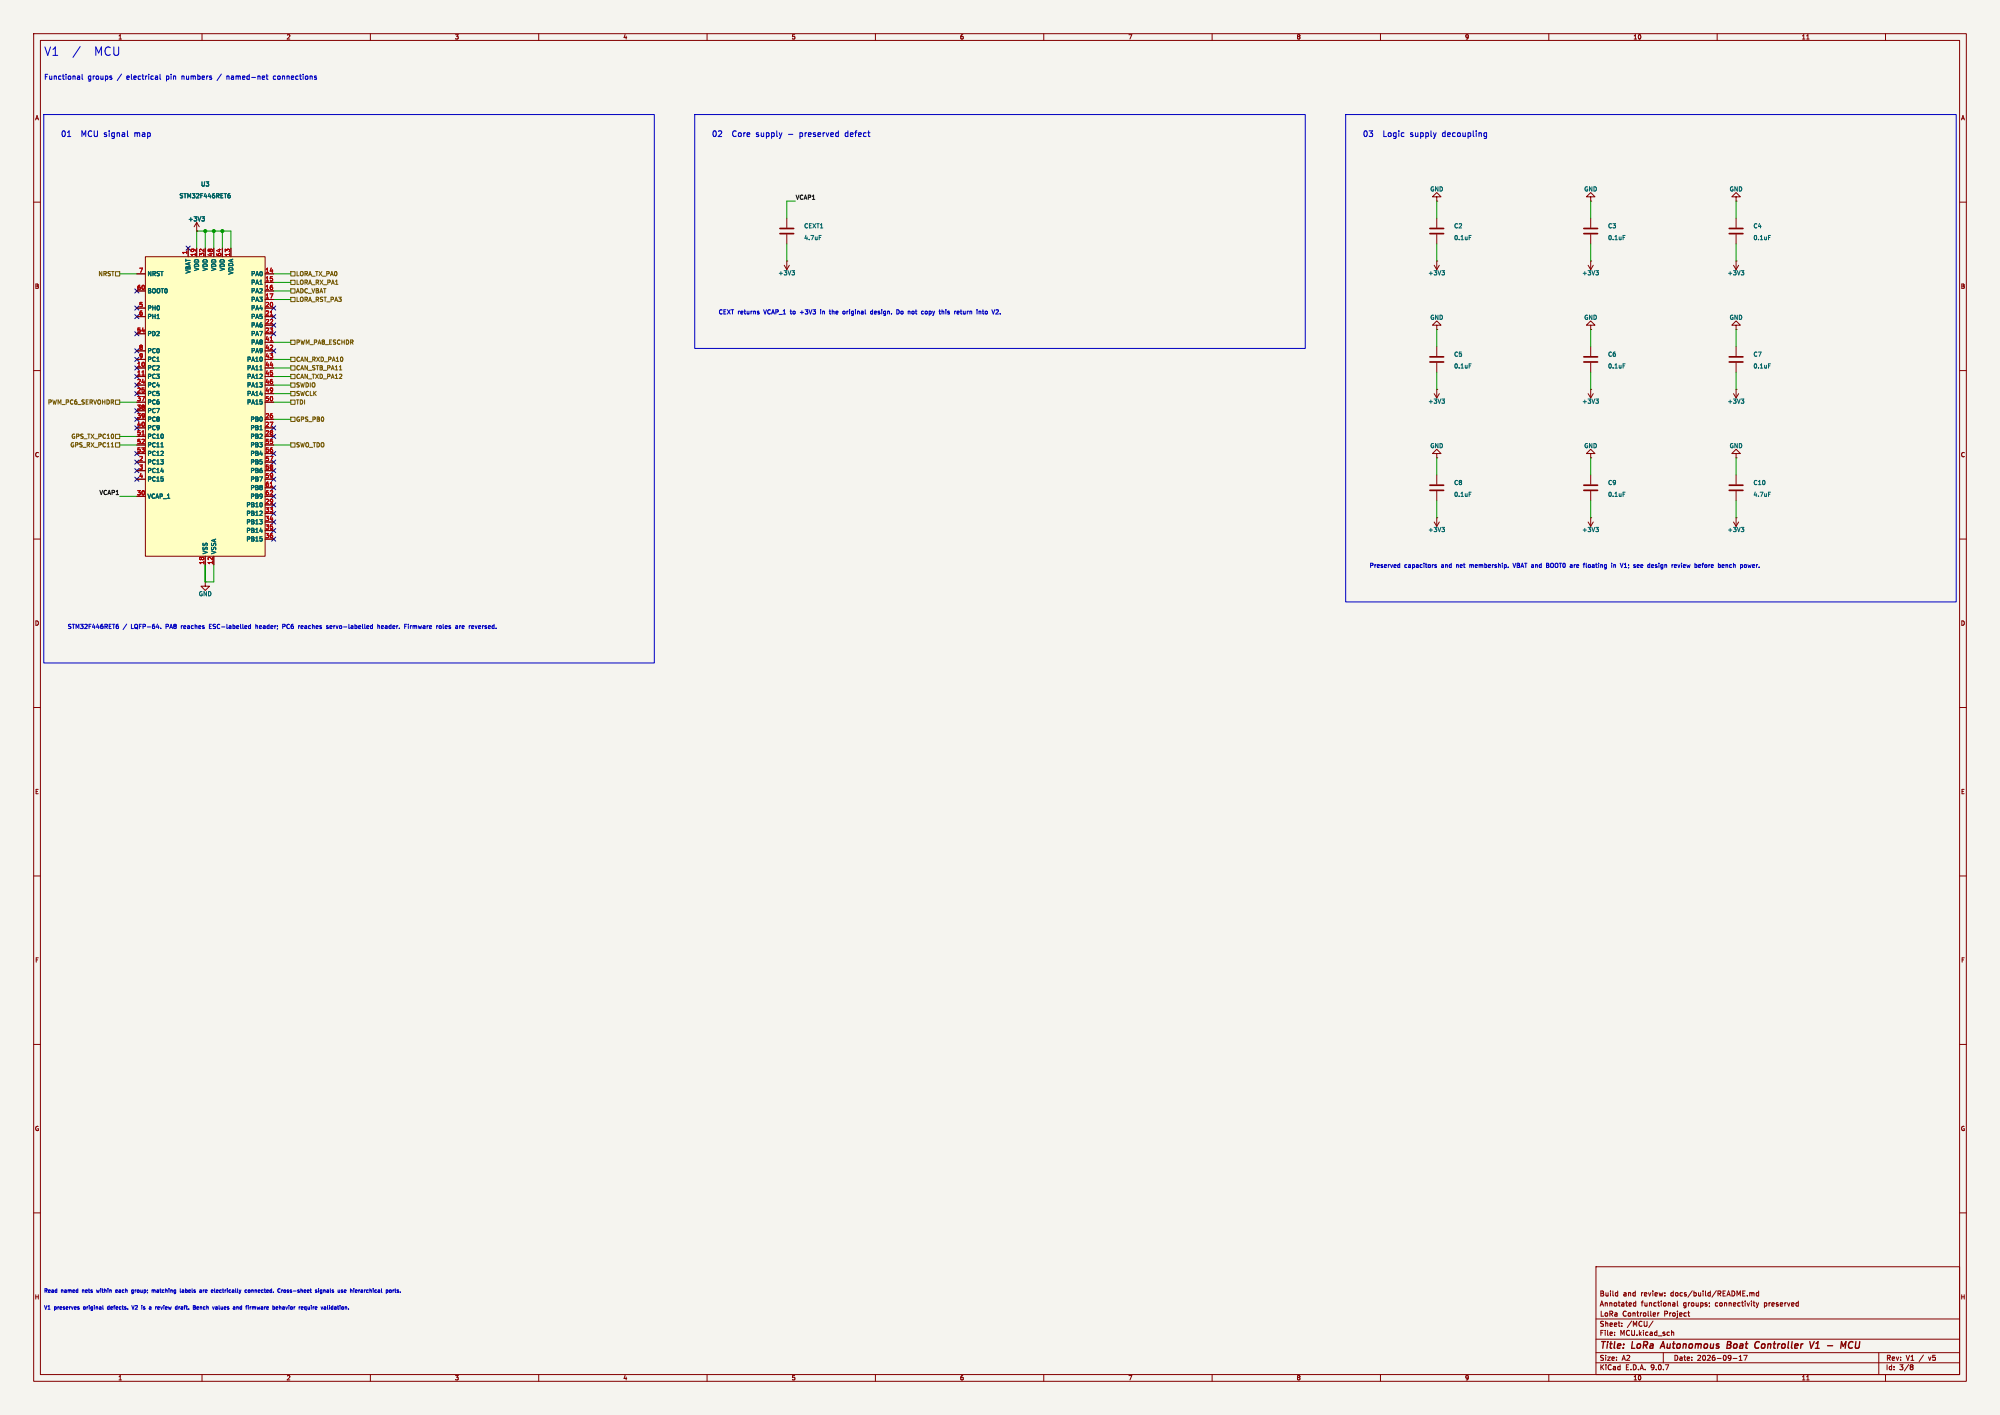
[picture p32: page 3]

1 VDD 19 VDD 32 VSS 18 VDD 48 VSSA 12 VDD 64 VDDA 13 PA0 14 PA1 15 PA2 16 PA3 17 PA4 20 PA5 21 PA6 22 PA7 23 PA8 41 PA9 42 PA10 43 PA11 44 PA12 45 PA13 46 PA14 49 PA15 50 PB0 26 PB1 27 PB2 28 PB3 55 PB4 56 PB5 57 PB6 58 PB7 59 PB8 61 PB9 62 PB10 29 PB12 33 PB13 34 PB14 35 PB15 36

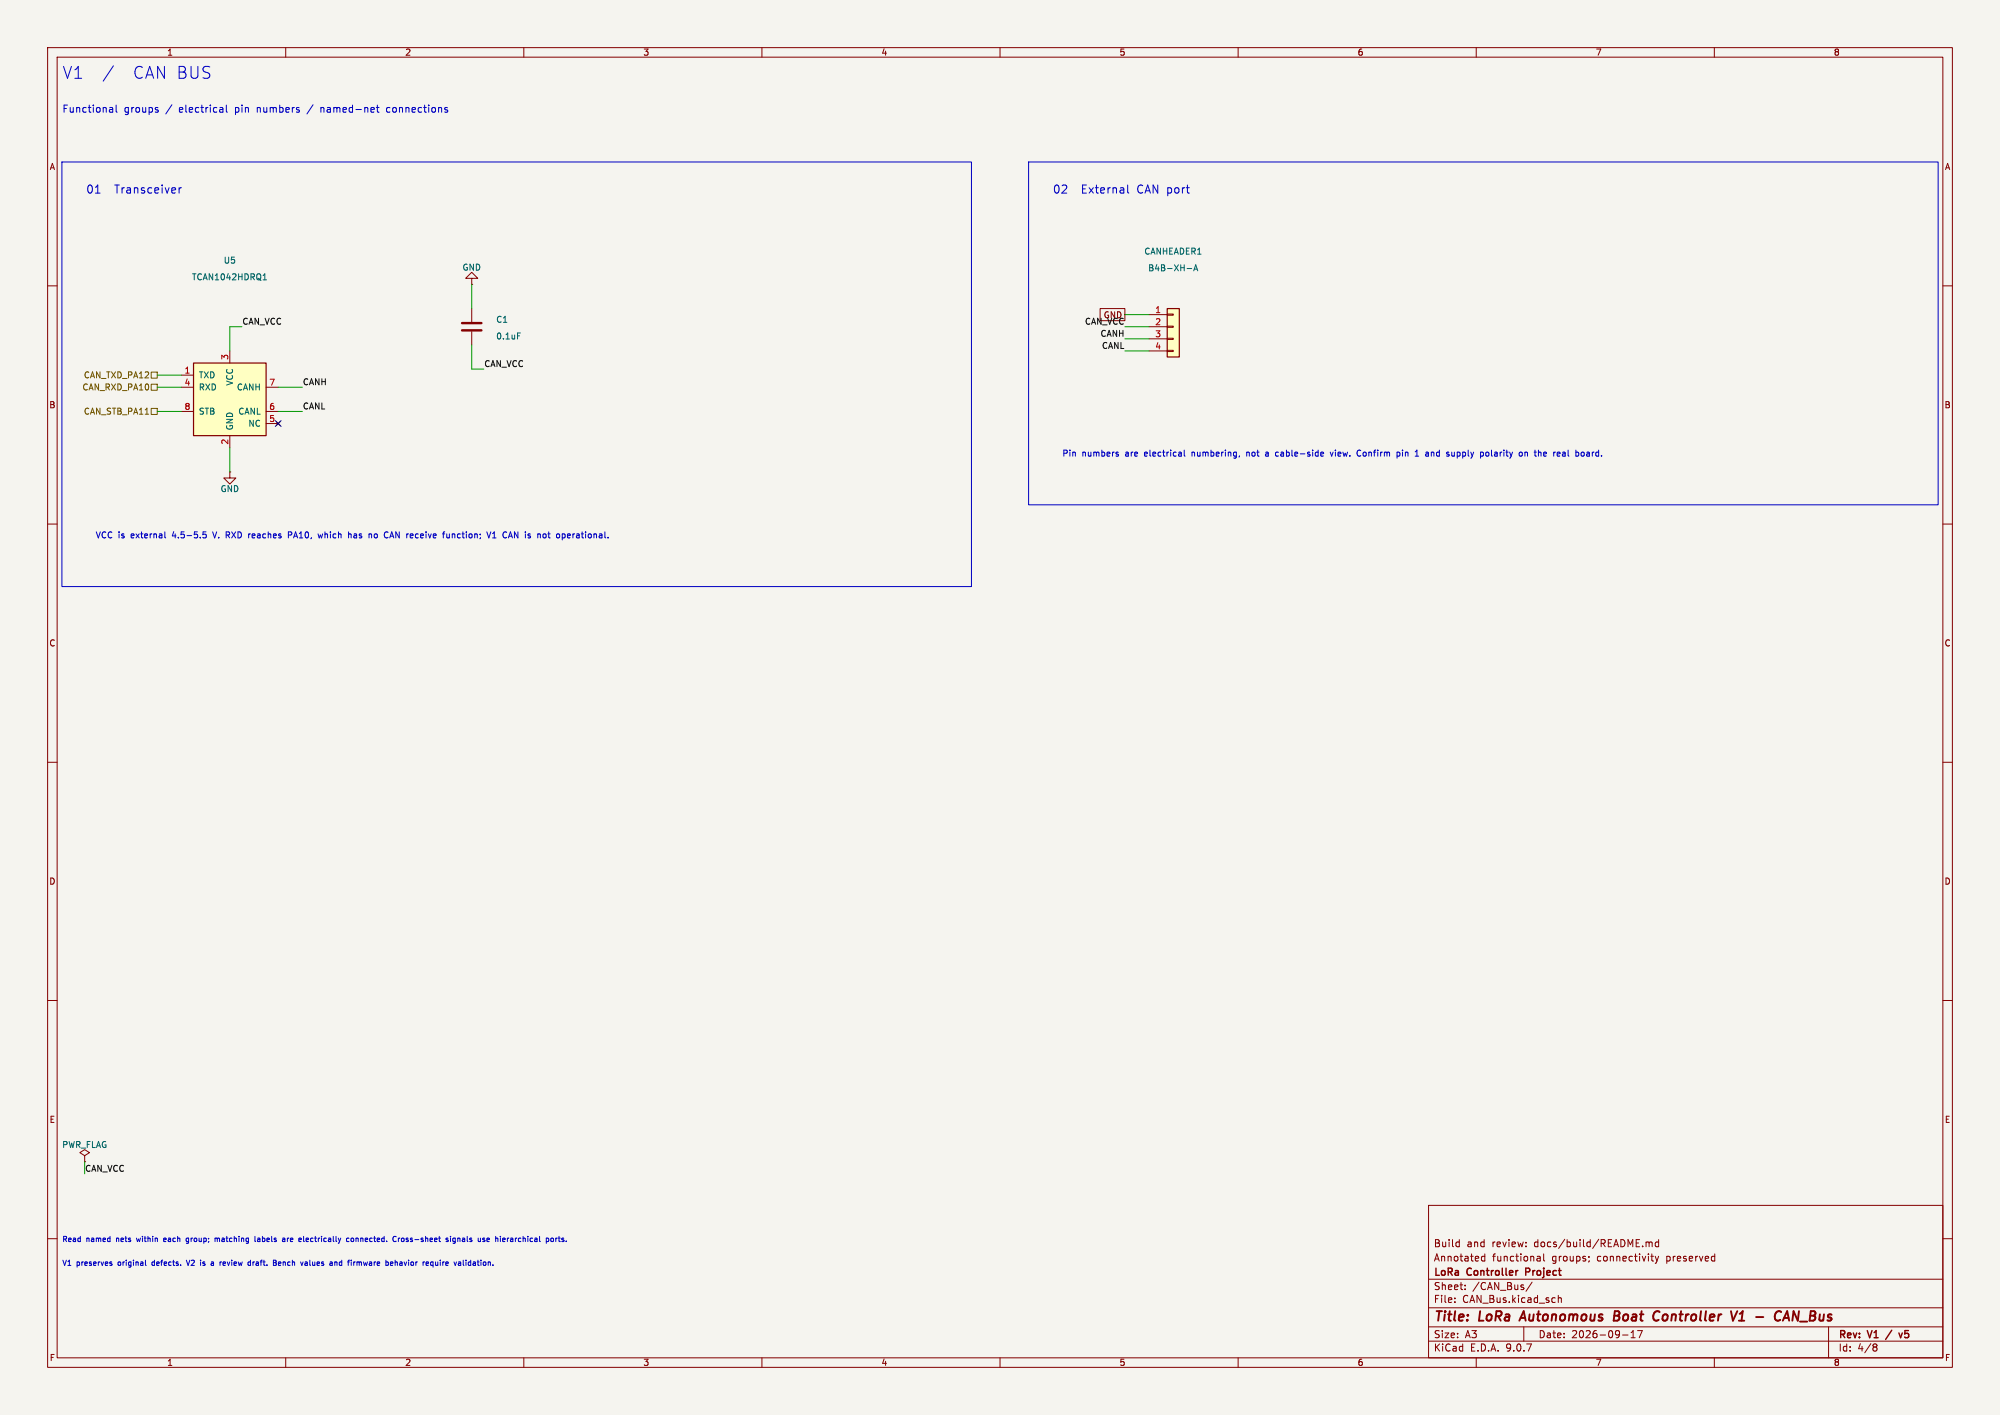
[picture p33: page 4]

Id: 4/8 Title: LoRa Autonomous Boat Controller V1 - CAN_Bus

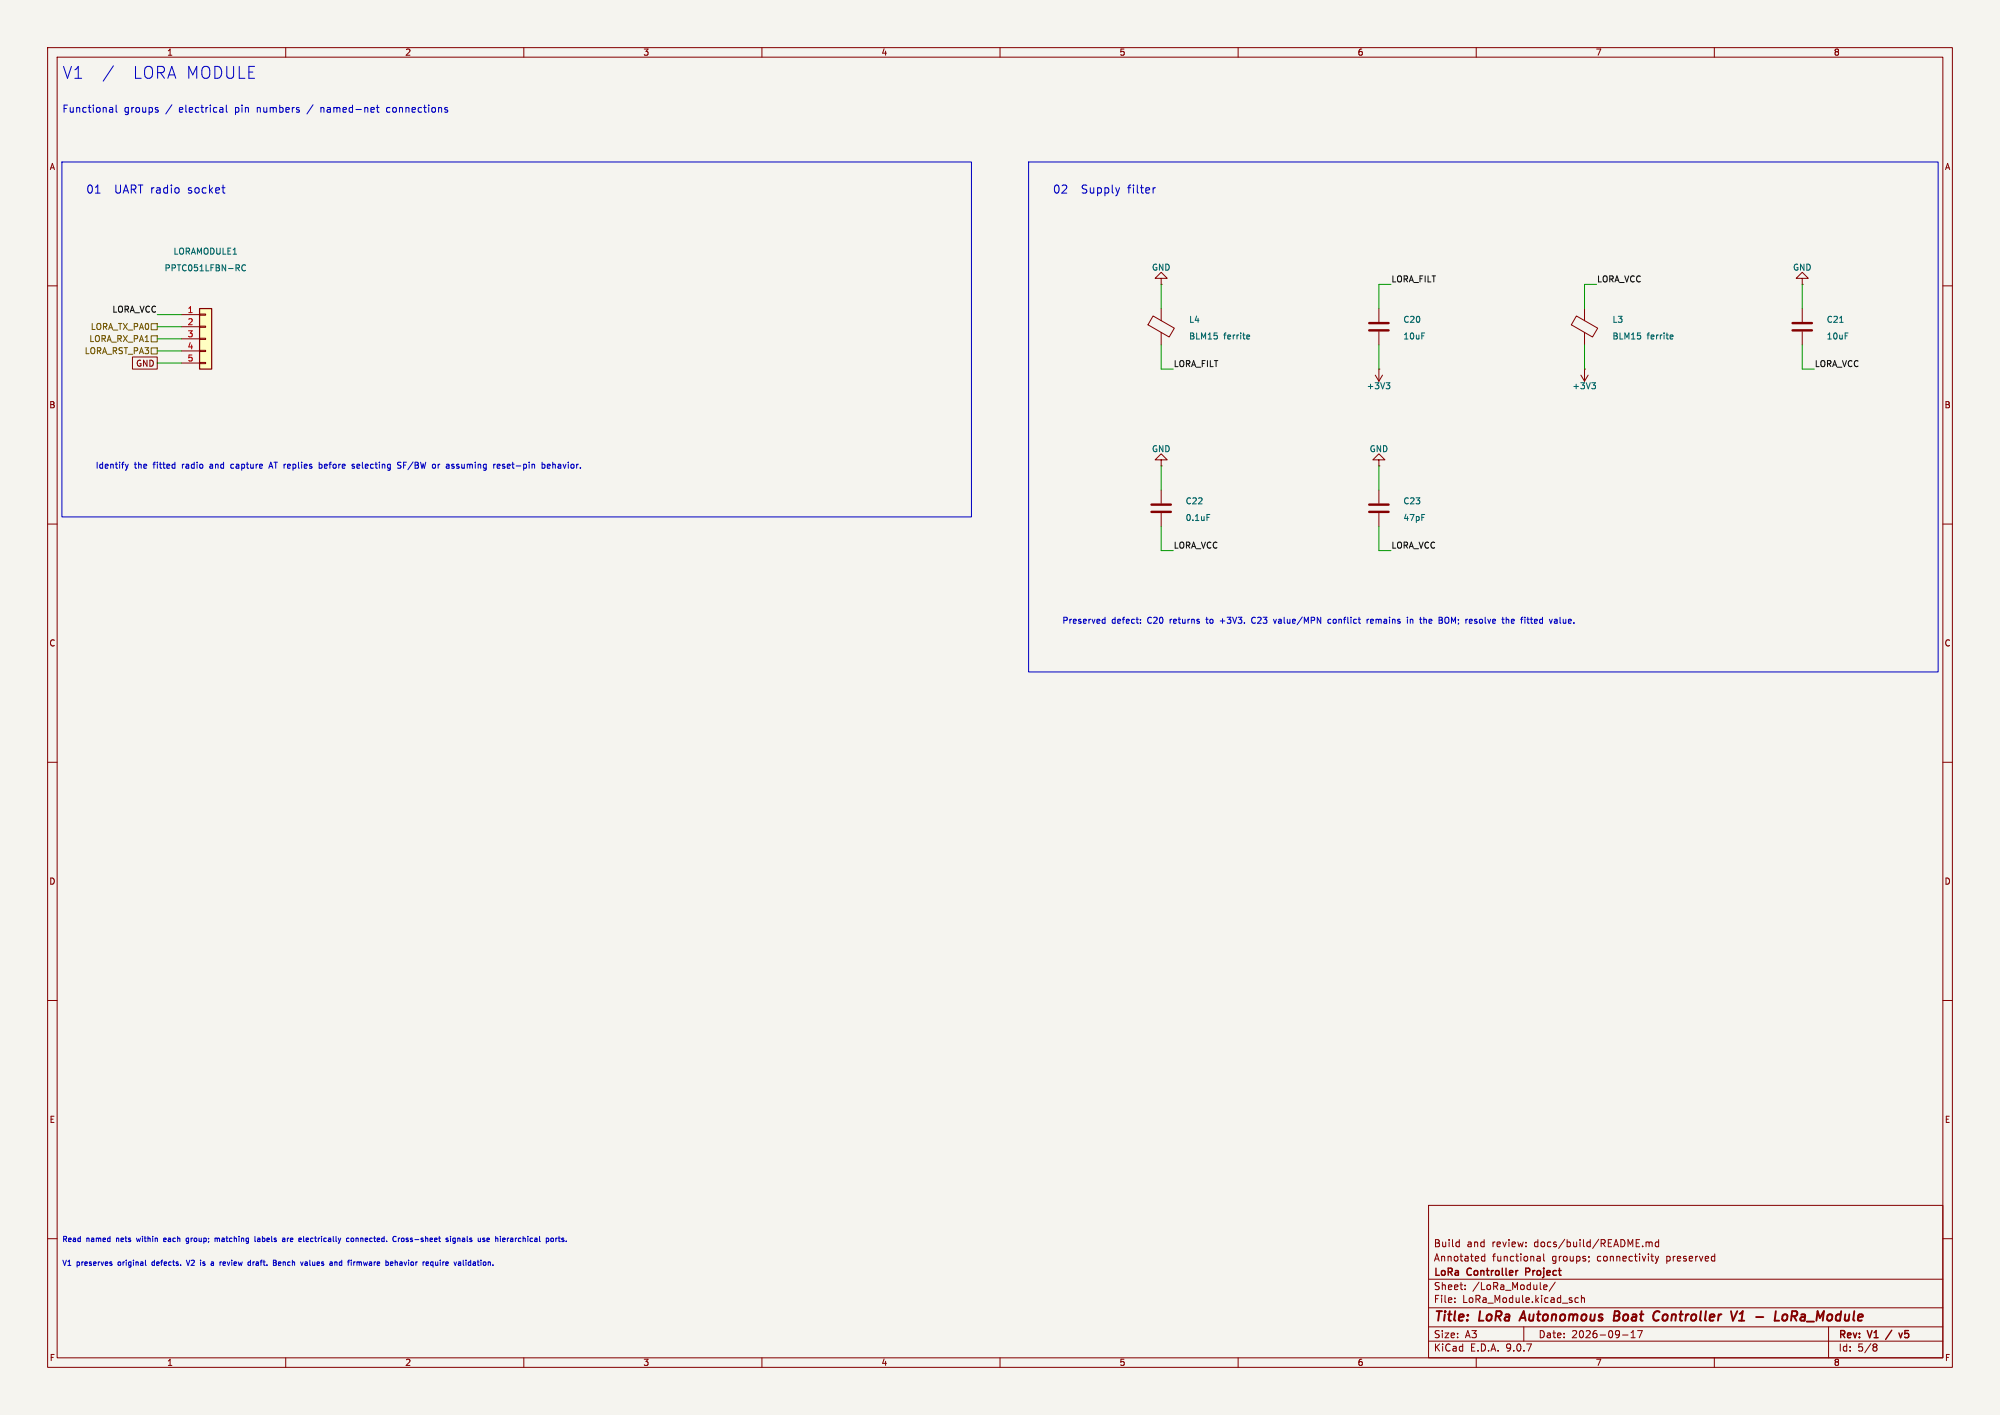
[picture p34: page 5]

Id: 5/8 Title: LoRa Autonomous Boat Controller V1 - LoRa_Module


Id: 6/8 Title: LoRa Autonomous Boat Controller V1 - GPS_Module


Id: 7/8 Title: LoRa Autonomous Boat Controller V1 - PWM_Outputs


Id: 8/8 Title: LoRa Autonomous Boat Controller V1 - Debug

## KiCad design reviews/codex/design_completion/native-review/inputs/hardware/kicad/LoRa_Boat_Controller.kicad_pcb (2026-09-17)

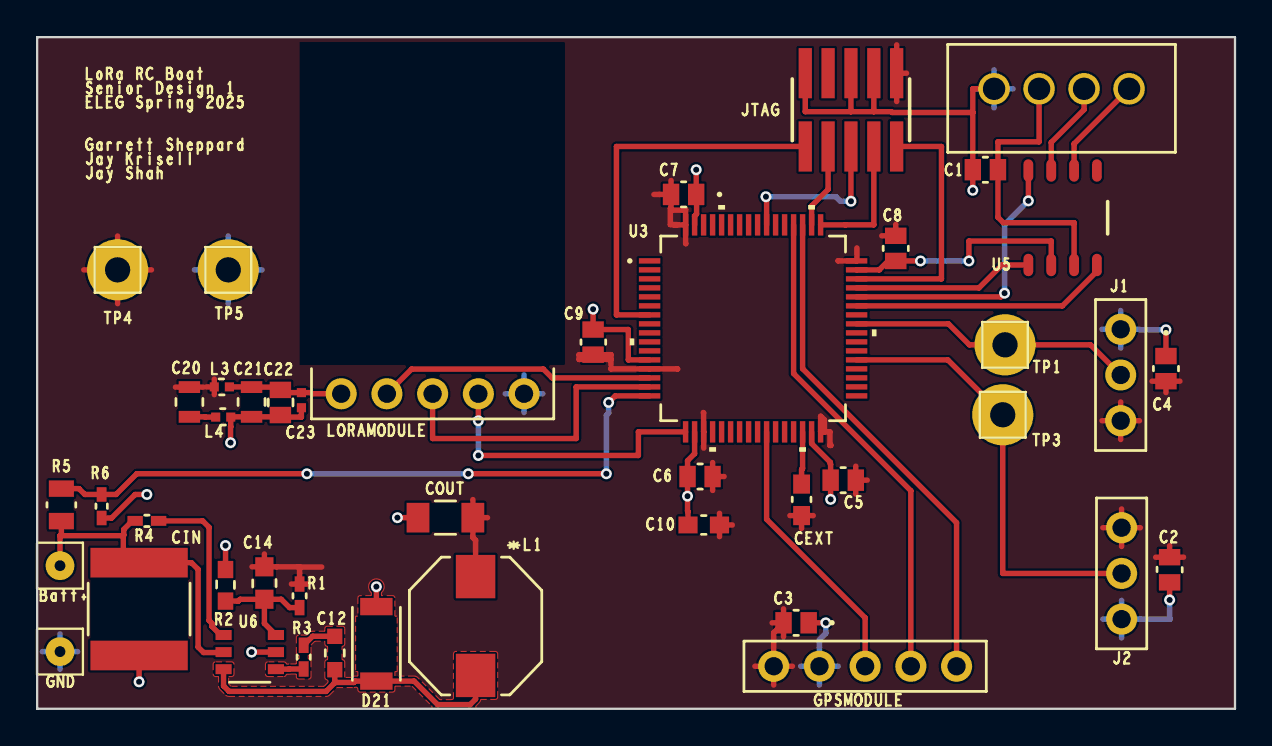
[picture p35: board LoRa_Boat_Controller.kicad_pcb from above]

Board: 2 copper layers, 66.5 x 37.3 mm, 44 parts (0 on the bottom side), 31 nets.

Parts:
C1, C2, C3, C4, C5, C6, C7, C8, C9, C22: .1uF; CAP_KGM21_KAV-L
C10: 4.7uF; CAP_0603_CL10A_1P6XP8_SAM-M
C12: .1uf; CAP_CL10_SAM-M
C14: 470pF; CAP_0603G_AVX-M
C20, C21: 10uF; G-21_MUR-L
C23: 47pF; CAP_GJM1555C1H220JB01__MUR-L
CANHEADER1: CONN_B4B-XH-A; CONN_B4B-XH-A_JST
CEXT1: 4.7 uF; CAP_0603_CL10A_1P6XP8_SAM-M
CIN1: 10uF; CAP_NTS_55_2P8T_NIP
COUT1: 10uf; G-31_MUR-M
D21: DIODE_MFLAT; M-FLAT_TOS-L
GND1: Battery-; amv_con1
GPSMODULE1: CONN5_1LFBN-RC; CONN5_1LFBN-RC_SUL
JTAG1: FTSH-105-XX-X-DV; SAMTEC_FTSH-105-XX-X-DV
L1: 4.7uh; IND_7045_TDK
L3, L4: INDUCTOR; IND_BLM15_0402_MUR-L
LORAMODULE1: CONN5_1LFBN-RC; CONN5_1LFBN-RC_SUL
R1: 15K; RC0402N_PAN-M
R2: 4.7K; RC0603N_YAG-M
R3: 51; RC0402N_YAG-M
R4: 5.1K; RC0402N_PAN-M
R5: 30K; RES_R0805_ROM-M
R6: 10K; RES_1005_SAM-M
SPEEDCONTROLLER1: CONN_PPTC031; CONN_PPTC031_SUL
STEERINGSERVO1: CONN_PPTC031; CONN_PPTC031_SUL
TP1, TP3, TP4, TP5: TEST POINT; amv_test_point
U3: STM32F4XXR2; LQFP64-10x10mm
U5: TCAN1042H-Q1D; D0008A_L
U6: R1240N001x; SOT-23-6W_PE-SOT23-6W-0512_NMD
VIN1: Battery+; amv_con1

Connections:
+3V3: C2.2, C3.2, C4.2, C5.2, C6.2, C7.2, C8.2, C9.2, C10.2, C14.1, C20.2, CEXT1.2, COUT1.2, GPSMODULE1.1, JTAG1.1, L1.1, L3.2, R1.1, SPEEDCONTROLLER1.1, STEERINGSERVO1.1, TP4.1, U3.13 (VDDA/VREF+), U3.19 (VDD), U3.32 (VDD_2), U3.48 (VDD_3), U3.64 (VDD_4)
ADC_VBAT: R5.2, R6.2, U3.16 (PA2)
BST: R3.2, U6.4 (BST)
BST_RC: C12.2, R3.1
CANH: CANHEADER1.3, U5.7 (CANH)
CANL: CANHEADER1.4, U5.6 (CANL)
CAN_RXD_PA10: U3.43 (PA10), U5.4 (RXD)
CAN_STB_PA11: U3.44 (PA11), U5.8 (STB)
CAN_TXD_PA12: U3.45 (PA12), U5.1 (TXD)
CAN_VCC: C1.2, CANHEADER1.2, U5.3 (VCC)
EN: R4.2, U6.1 (CE)
FB_DIV: C14.2, R1.2, R2.1, U6.6 (VFB)
GND: C1.1, C2.1, C3.1, C4.1, C5.1, C6.1, C7.1, C8.1, C9.1, C10.1, C21.1, C22.1, C23.1, CANHEADER1.1, CIN1.1, COUT1.1, D21.1, GND1.1, GPSMODULE1.2, JTAG1.3, JTAG1.5, JTAG1.9, L4.1, LORAMODULE1.5, R2.2, R6.1, SPEEDCONTROLLER1.3, STEERINGSERVO1.3, TP5.1, U3.12 (VSSA/VREF-), U3.18 (VSS), U3.31 (VSS_2), U3.47 (VSS_3), U3.63 (VSS_4), U5.2 (GND), U6.5 (GND)
GPS_PB0: GPSMODULE1.3, U3.26 (PB0)
GPS_RX_PC11: GPSMODULE1.4, U3.52 (PC11)
GPS_TX_PC10: GPSMODULE1.5, U3.51 (PC10)
LORA_FILT: C20.1, L4.2
LORA_RST_PA3: LORAMODULE1.4, U3.17 (PA3)
LORA_RX_PA1: LORAMODULE1.3, U3.15 (PA1)
LORA_TX_PA0: LORAMODULE1.2, U3.14 (PA0)
LORA_VCC: C21.2, C22.2, C23.2, L3.1, LORAMODULE1.1
NRST: JTAG1.10, U3.7 (NRST)
PWM_PA8_ESCHDR: SPEEDCONTROLLER1.2, TP1.1, U3.41 (PA8)
PWM_PC6_SERVOHDR: STEERINGSERVO1.2, TP3.1, U3.37 (PC6)
SWCLK: JTAG1.4, U3.49 (PA14)
SWDIO: JTAG1.2, U3.46 (PA13)
SWO_TDO: JTAG1.6, U3.55 (PB3)
SW_NODE: C12.1, D21.2, L1.2, U6.3 (LX)
TDI: JTAG1.8, U3.50 (PA15)
VCAP1: CEXT1.1, U3.30 (VCAP_1)
VIN_RAW: CIN1.2, R4.1, R5.1, U6.2 (VIN), VIN1.1

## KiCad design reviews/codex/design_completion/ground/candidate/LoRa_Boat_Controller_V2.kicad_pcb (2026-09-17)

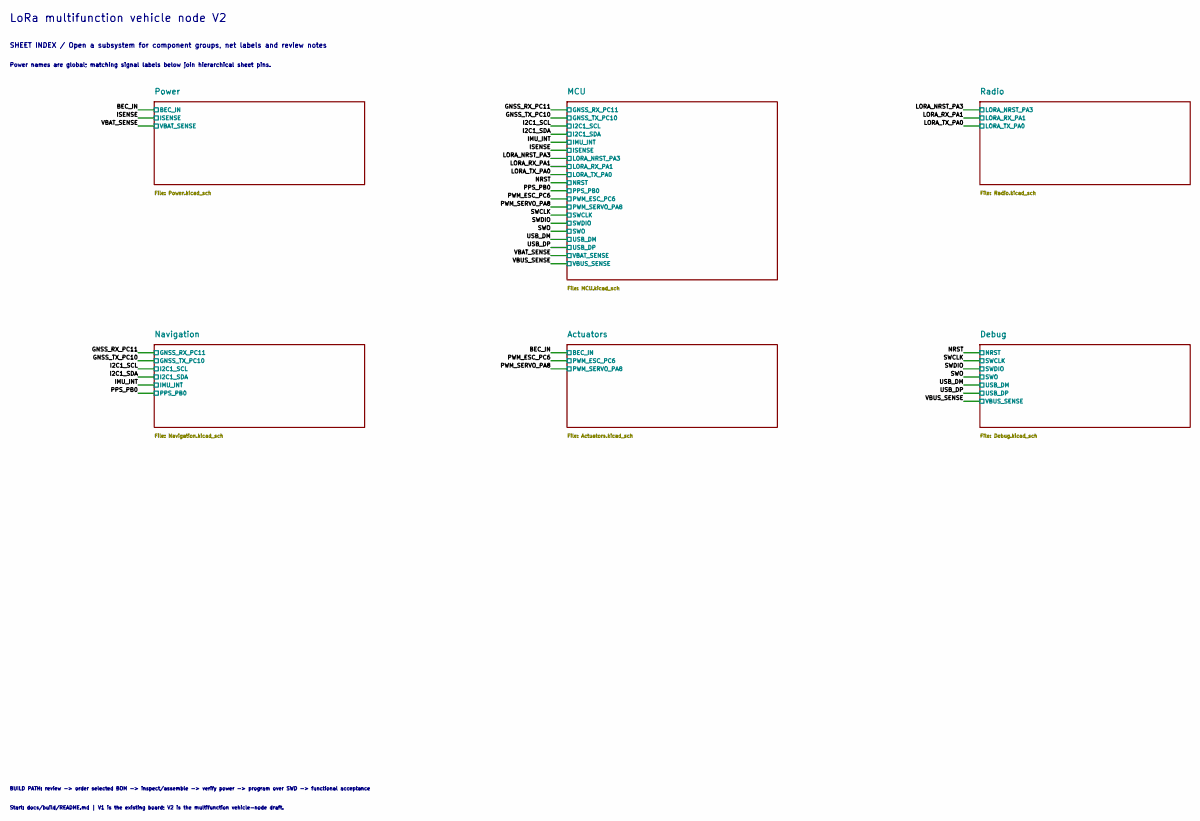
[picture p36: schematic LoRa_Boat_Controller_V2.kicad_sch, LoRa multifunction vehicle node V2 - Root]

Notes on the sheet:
LoRa multifunction vehicle node V2
SHEET INDEX / Open a subsystem for component groups, net labels and review notes
Power names are global; matching signal labels below join hierarchical sheet pins.
BUILD PATH: review -> order selected BOM -> inspect/assemble -> verify power -> program over SWD -> functional acceptance
Start: docs/build/README.md | V1 is the existing board; V2 is the multifunction vehicle-node draft.

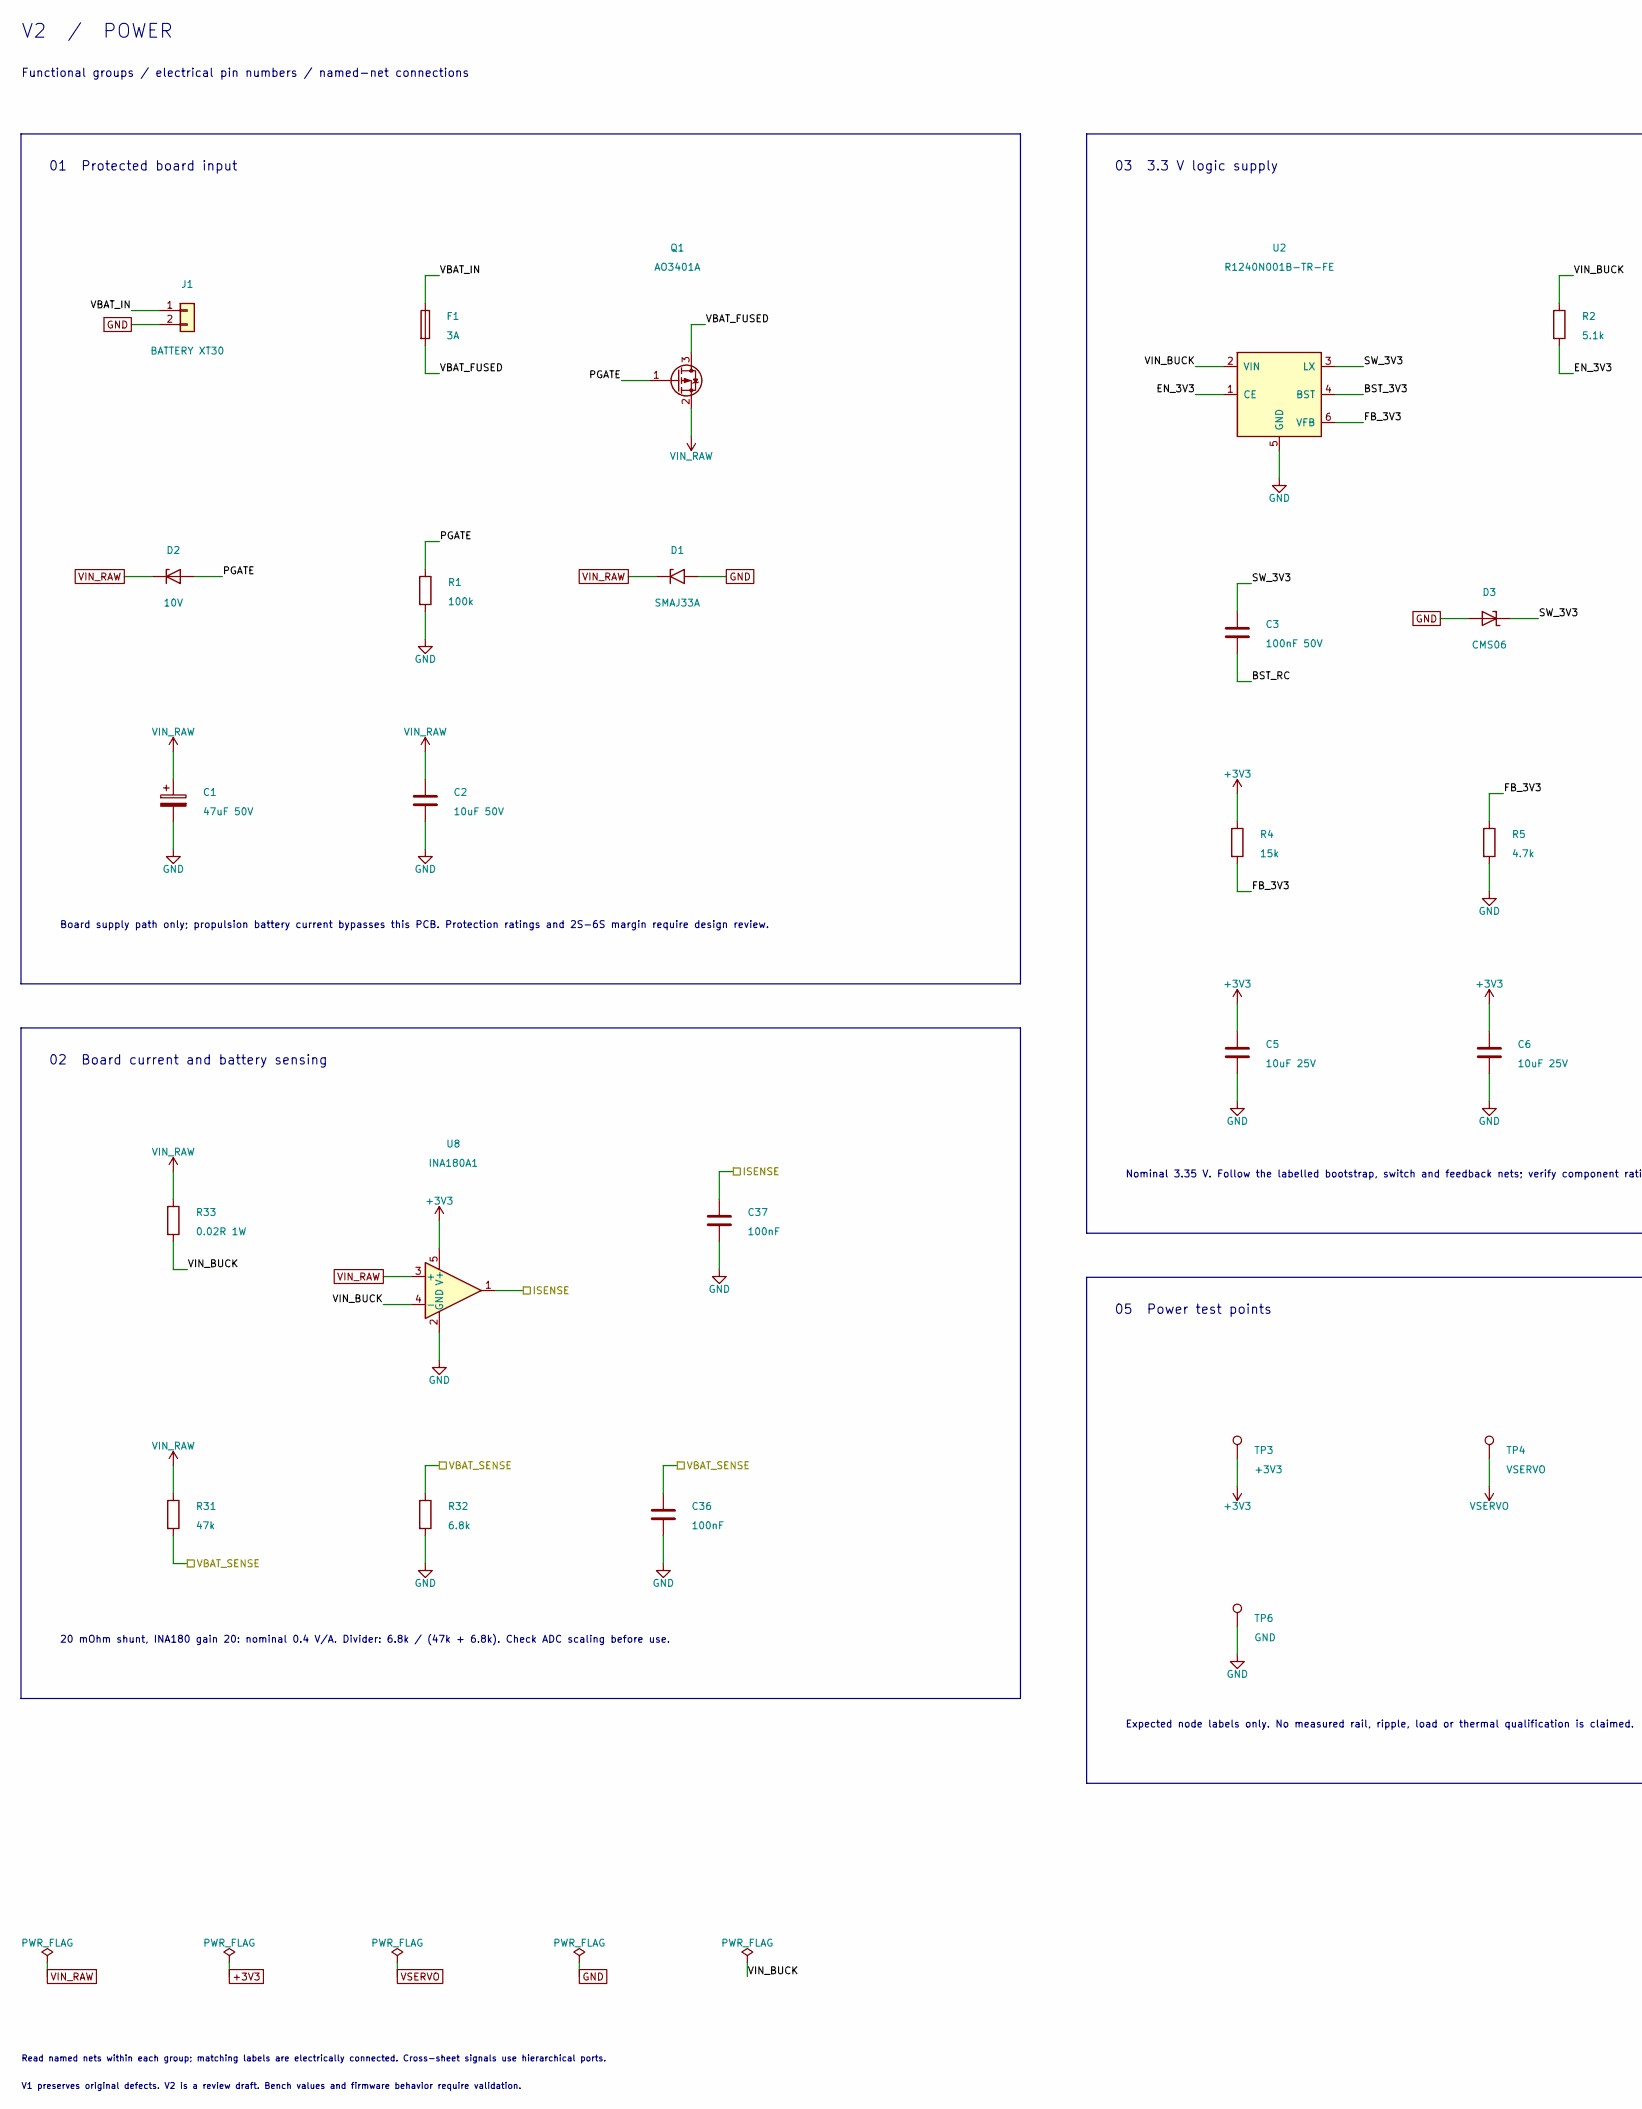
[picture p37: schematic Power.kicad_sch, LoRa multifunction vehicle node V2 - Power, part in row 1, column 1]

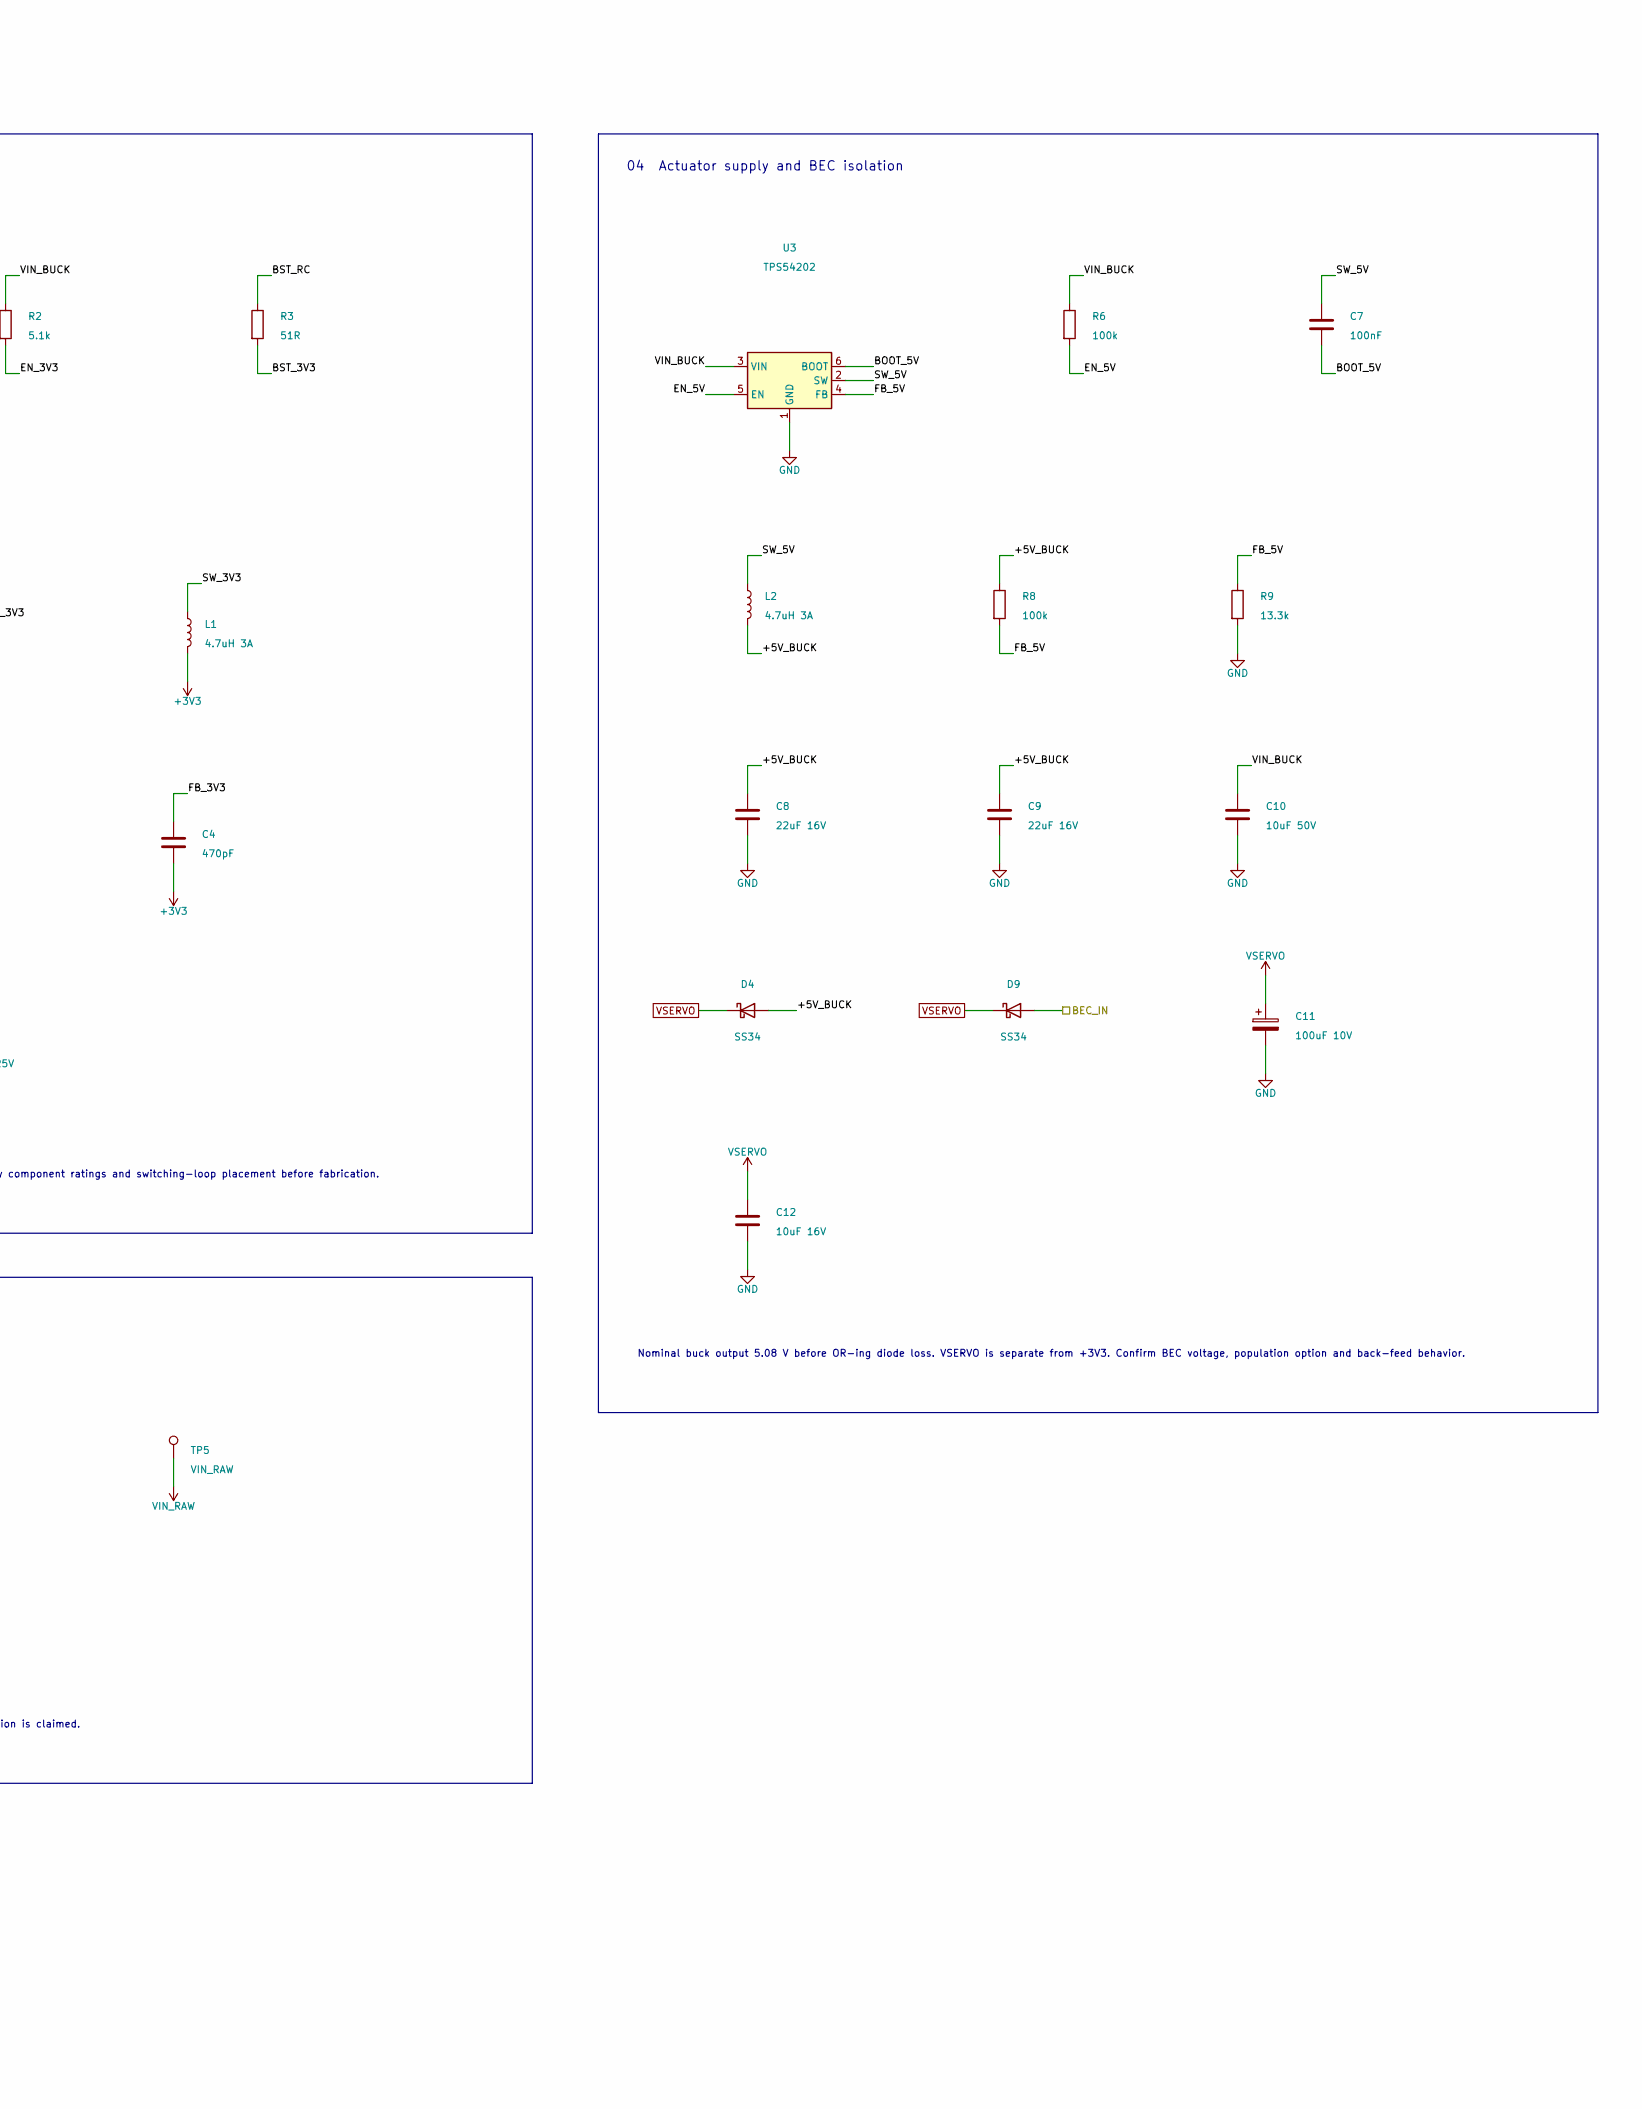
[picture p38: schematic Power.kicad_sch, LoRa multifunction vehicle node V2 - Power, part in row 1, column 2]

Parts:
C1: 47uF 50V; CP_Elec_6.3x7.7; MPN EEE-FK1H470P
C2, C10: 10uF 50V; C_1210_3225Metric; MPN GRM32ER71H106KA12L
C3: 100nF 50V; C_0603_1608Metric; MPN CL10B104KB8NNNC
C4: 470pF; C_0603_1608Metric; MPN 06035A471JAT2A
C5, C6: 10uF 25V; C_1206_3216Metric; MPN GRM31CR71E106KA12L
C7, C36, C37: 100nF; C_0603_1608Metric; MPN KGM15ACG1H104KT
C8, C9: 22uF 16V; C_1210_3225Metric; MPN GRM32ER61C226KE20L
C11: 100uF 10V; CP_Elec_6.3x7.7; MPN EEE-FK1A101P
C12: 10uF 16V; C_0805_2012Metric; MPN GRM21BR61C106KE15L
D1: SMAJ33A; D_SMA; MPN SMAJ33A
D2: 10V; D_SOD-123; MPN BZT52C10-7-F
D3: CMS06; M-FLAT_TOS-L; MPN CMS06(TE12L,Q,M)
D4, D9: SS34; D_SMA; MPN SS34
F1: 3A; Fuse_1812_4532Metric; MPN 0468003.NR
J1: BATTERY XT30; AMASS_XT30PW-M_1x02_P2.50mm_Horizontal; MPN XT30PW-M
L1, L2: 4.7uH 3A; L_Bourns_SRN6045TA; MPN SRN6045TA-4R7M
Q1: AO3401A; SOT-23; MPN AO3401A
R1, R6, R8: 100k; R_0603_1608Metric; MPN RC0603FR-07100KL
R2: 5.1k; R_0603_1608Metric; MPN RC0603FR-075K1L
R3: 51R; R_0603_1608Metric; MPN RC0603FR-0751RL
R4: 15k; R_0603_1608Metric; MPN RC0603FR-0715KL
R5: 4.7k; R_0603_1608Metric; MPN RC0603FR-074K7L
R9: 13.3k; R_0603_1608Metric; MPN RC0603FR-0713K3L
R31: 47k; R_0603_1608Metric; MPN RC0603FR-0747KL
R32: 6.8k; R_0603_1608Metric; MPN RC0603FR-076K8L
R33: 0.02R 1W; R_2512_6332Metric; MPN CRA2512-FZ-R020ELF
TP3: +3V3; TestPoint_Pad_D1.5mm
TP4: VSERVO; TestPoint_Pad_D1.5mm
TP5: VIN_RAW; TestPoint_Pad_D1.5mm
TP6: GND; TestPoint_Pad_D1.5mm
U2: R1240N001B-TR-FE; SOT-23-6W_PE-SOT23-6W-0512_NMD; MPN R1240N001B-TR-FE
U3: TPS54202; TSOT-23-6; MPN TPS54202DDCR
U8: INA180A1; SOT-23-5; MPN INA180A1IDBVR

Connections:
+3V3: C4.2, C5.1, C6.1, L1.2, R4.1, TP3.1, U8.5 (V+); also elsewhere on the board
+5V_BUCK: C8.1, C9.1, D4.2 (A), L2.2, R8.1
BEC_IN: D9.2 (A); also elsewhere on the board
BOOT_5V: C7.2, U3.6 (BOOT)
BST_3V3: R3.2, U2.4 (BST)
BST_RC: C3.2, R3.1
EN_3V3: R2.2, U2.1 (CE)
EN_5V: R6.2, U3.5 (EN)
FB_3V3: C4.1, R4.2, R5.1, U2.6 (VFB)
FB_5V: R8.2, R9.1, U3.4 (FB)
GND: C1.2, C2.2, C5.2, C6.2, C8.2, C9.2, C10.2, C11.2, C12.2, C36.2, C37.2, D1.2 (A2), D3.1 (A), J1.2, R1.2, R5.2, R9.2, R32.2, TP6.1, U2.5 (GND), U3.1 (GND), U8.2 (GND); also elsewhere on the board
ISENSE: C37.1, U8.1; also elsewhere on the board
PGATE: D2.2 (A), Q1.1 (G), R1.1
SW_3V3: C3.1, D3.2 (K), L1.1, U2.3 (LX)
SW_5V: C7.1, L2.1, U3.2 (SW)
VBAT_FUSED: F1.2, Q1.3 (D)
VBAT_IN: F1.1, J1.1
VBAT_SENSE: C36.1, R31.2, R32.1; also elsewhere on the board
VIN_BUCK: C10.1, R2.1, R6.1, R33.2, U2.2 (VIN), U3.3 (VIN), U8.4 (-)
VIN_RAW: C1.1, C2.1, D1.1 (A1), D2.1 (K), Q1.2 (S), R31.1, R33.1, TP5.1, U8.3 (+)
VSERVO: C11.1, C12.1, D4.1 (K), D9.1 (K), TP4.1; also elsewhere on the board

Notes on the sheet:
V2 / POWER
Functional groups / electrical pin numbers / named-net connections
01 Protected board input
Board supply path only; propulsion battery current bypasses this PCB. Protection ratings and 2S-6S margin require design review.
02 Board current and battery sensing
20 mOhm shunt, INA180 gain 20: nominal 0.4 V/A. Divider: 6.8k / (47k + 6.8k). Check ADC scaling before use.
03 3.3 V logic supply
Nominal 3.35 V. Follow the labelled bootstrap, switch and feedback nets; verify component ratings and switching-loop placement before fabrication.
04 Actuator supply and BEC isolation
Nominal buck output 5.08 V before OR-ing diode loss. VSERVO is separate from +3V3. Confirm BEC voltage, population option and back-feed behavior.
05 Power test points
Expected node labels only. No measured rail, ripple, load or thermal qualification is claimed.
Read named nets within each group; matching labels are electrically connected. Cross-sheet signals use hierarchical ports.
V1 preserves original defects. V2 is a review draft. Bench values and firmware behavior require validation.

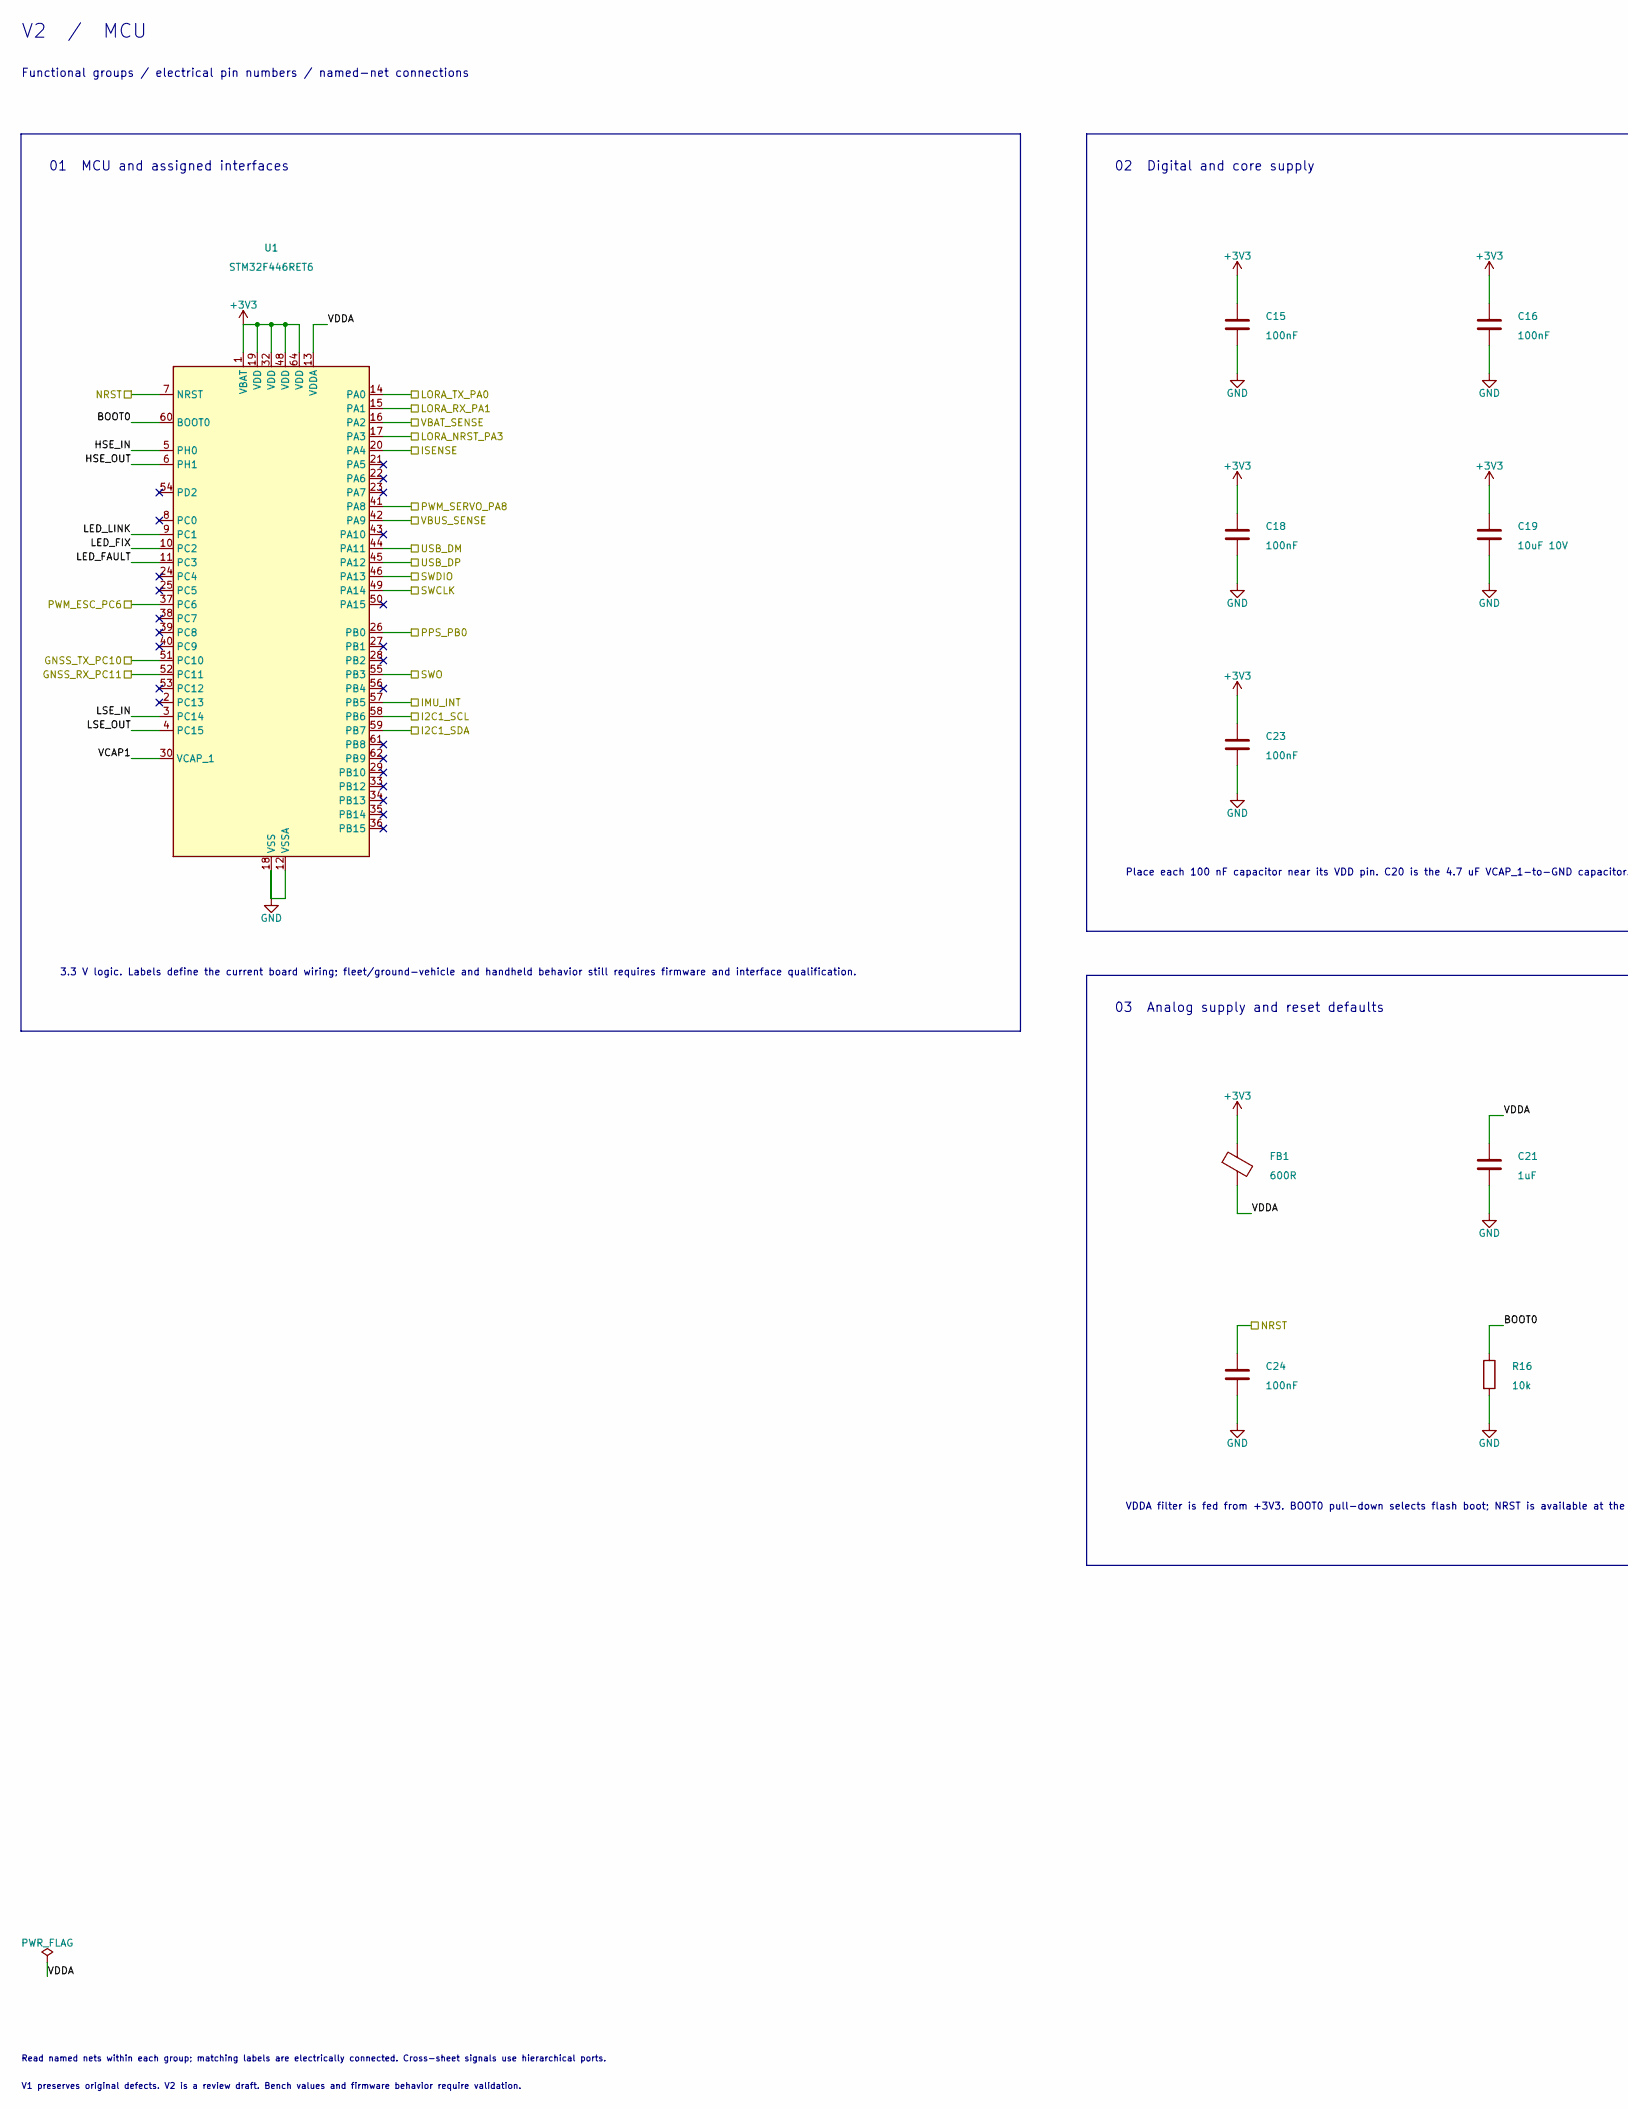
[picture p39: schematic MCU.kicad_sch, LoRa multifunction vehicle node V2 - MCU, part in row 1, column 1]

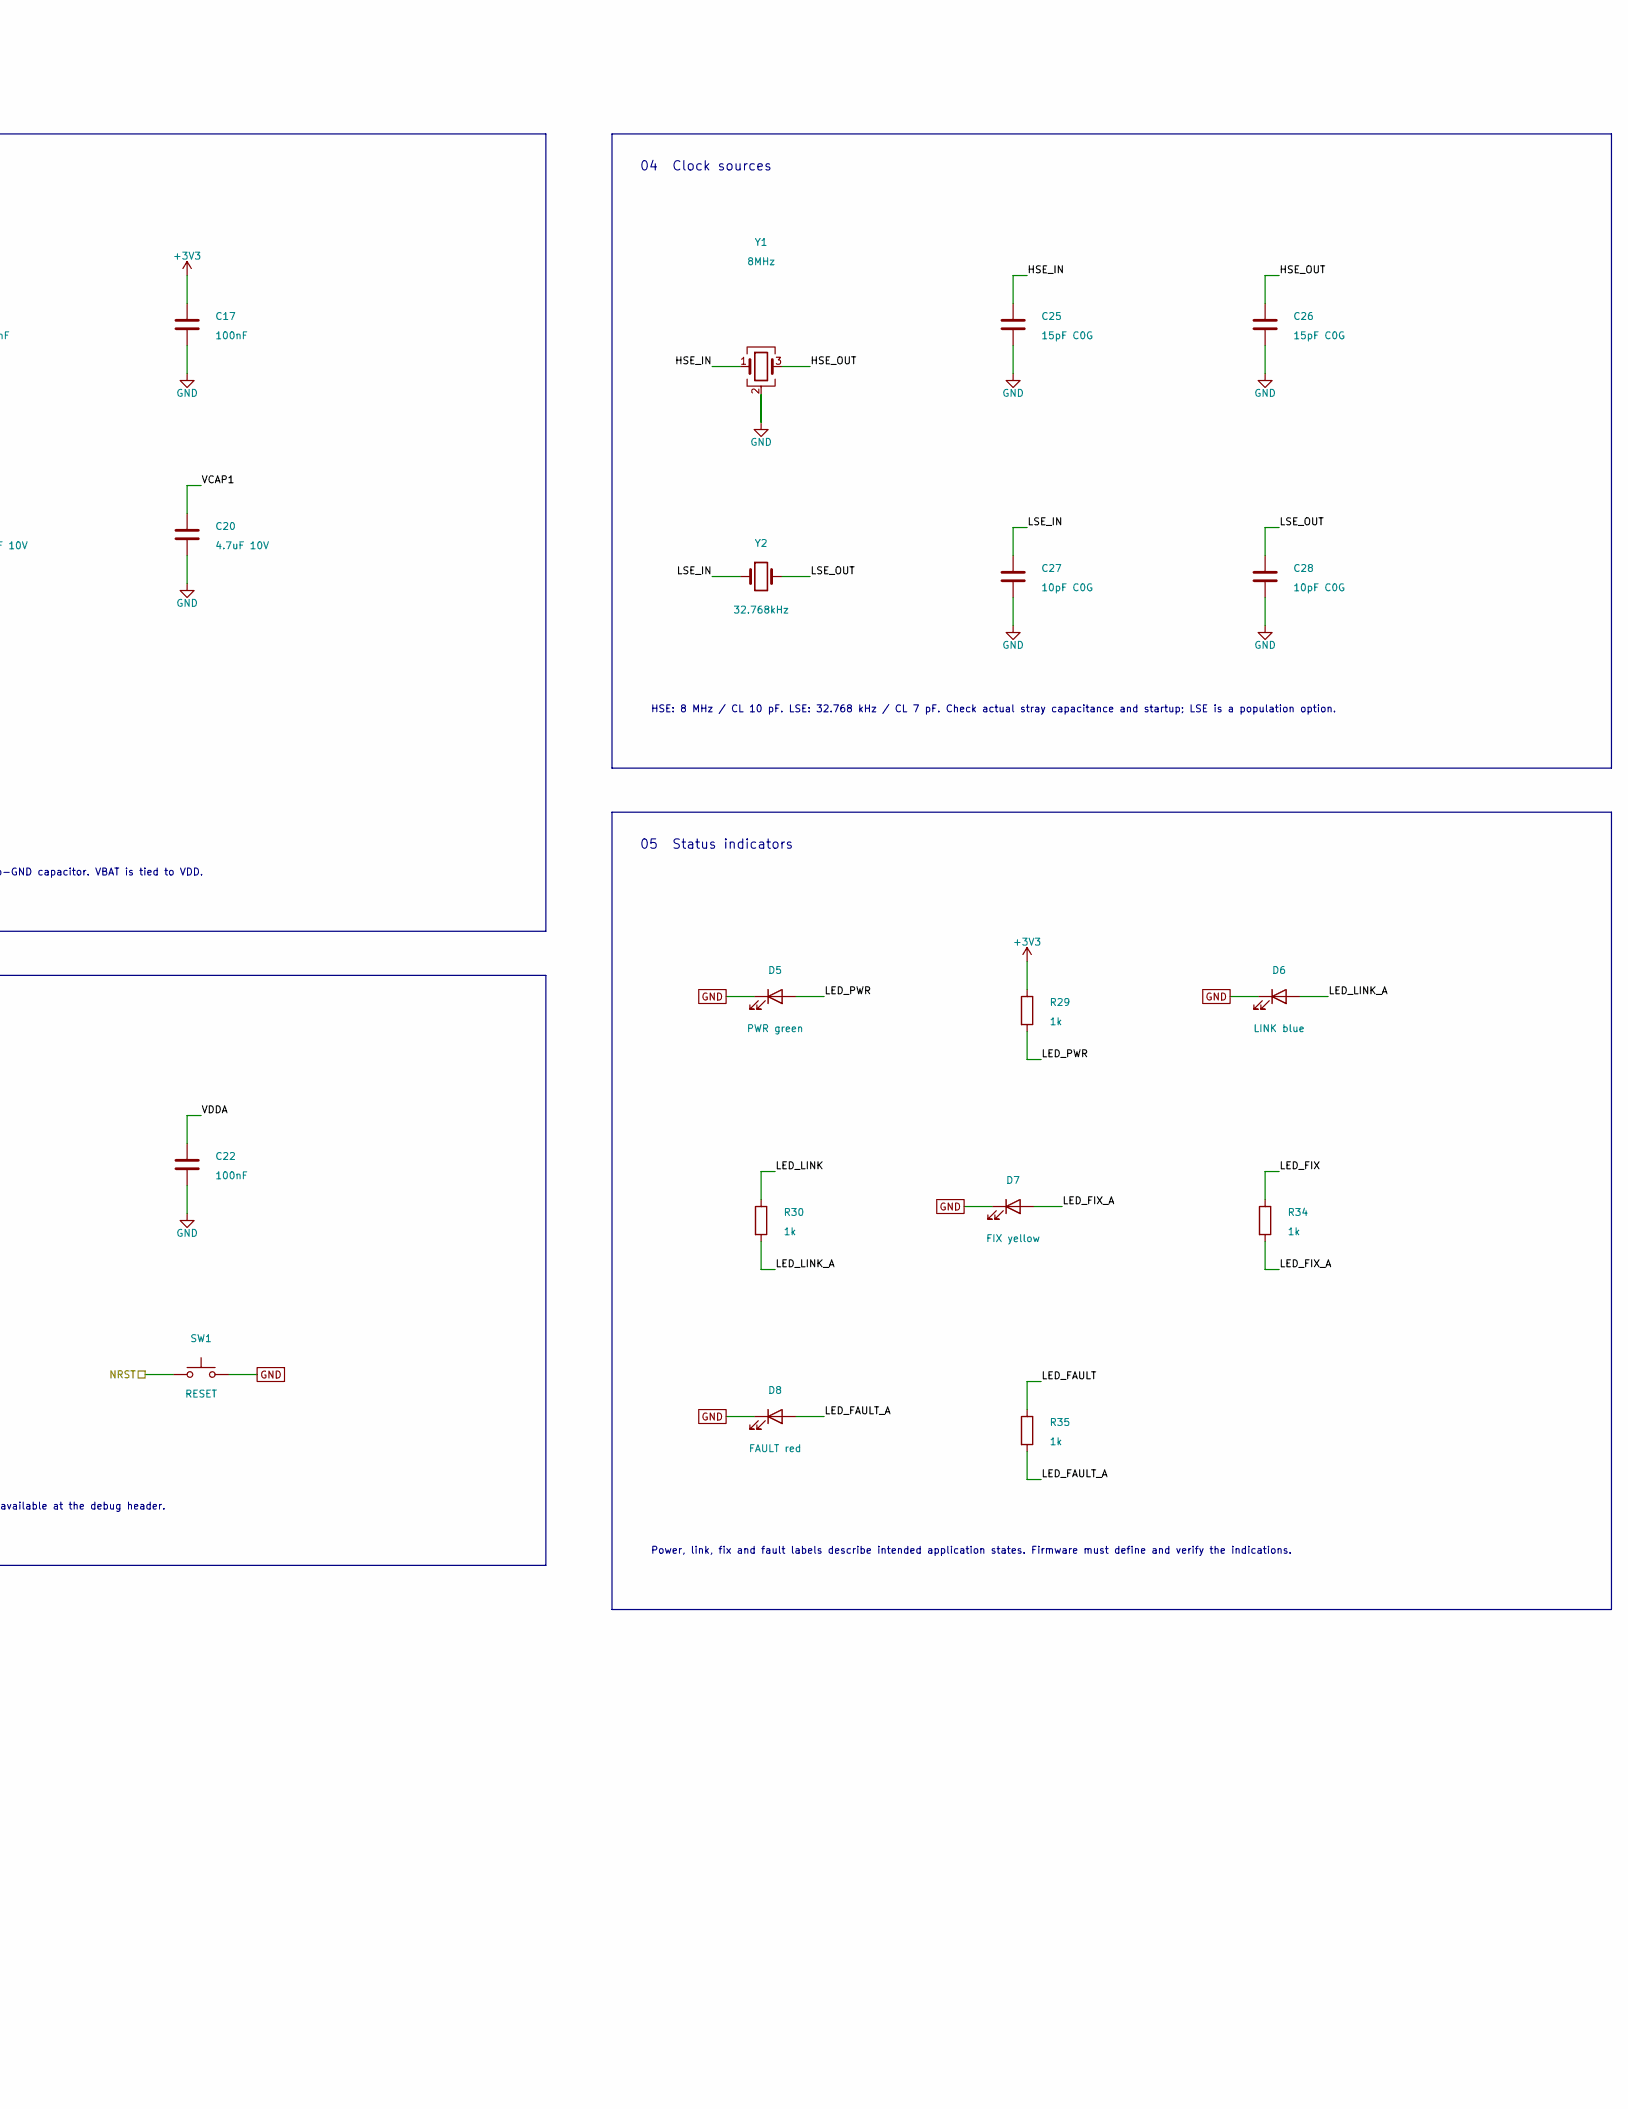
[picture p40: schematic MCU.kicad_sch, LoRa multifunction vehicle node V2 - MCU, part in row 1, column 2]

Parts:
C15, C16, C17, C18, C22, C23, C24: 100nF; C_0603_1608Metric; MPN KGM15ACG1H104KT
C19: 10uF 10V; C_0805_2012Metric; MPN GRM21BR61A106KE19L
C20: 4.7uF 10V; C_0603_1608Metric; MPN CL10A475KP8NNNC
C21: 1uF; C_0603_1608Metric; MPN CL10A105KB8NNNC
C25, C26: 15pF C0G; C_0603_1608Metric; MPN 06035A150JAT2A
C27, C28: 10pF C0G; C_0603_1608Metric; MPN 06035A100JAT2A
D5: PWR green; LED_0603_1608Metric; MPN LTST-C193KGKT-5A
D6: LINK blue; LED_0603_1608Metric; MPN LTST-C193TBKT-5A
D7: FIX yellow; LED_0603_1608Metric; MPN LTST-C193KSKT-5A
D8: FAULT red; LED_0603_1608Metric; MPN LTST-C193KRKT-5A
FB1: 600R; L_0603_1608Metric; MPN BLM18AG601SN1D
R16: 10k; R_0603_1608Metric; MPN RC0603FR-0710KL
R29, R30, R34, R35: 1k; R_0603_1608Metric; MPN RC0603FR-071KL
SW1: RESET; SW_Push_1P1T_NO_CK_KMR2; MPN KMR221GLFS
U1: STM32F446RET6; LQFP-64_10x10mm_P0.5mm; MPN STM32F446RET6
Y1: 8MHz; Crystal_SMD_3225-4Pin_3.2x2.5mm; MPN ABM8-8.000MHZ-10-1-U-T
Y2: 32.768kHz; Crystal_SMD_3215-2Pin_3.2x1.5mm; MPN ABS07-32.768KHZ-7-T

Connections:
+3V3: C15.1, C16.1, C17.1, C18.1, C19.1, C23.1, FB1.1, R29.1, U1.1 (VBAT), U1.19 (VDD), U1.32 (VDD), U1.48 (VDD), U1.64 (VDD); also elsewhere on the board
BOOT0: R16.1, U1.60 (BOOT0)
GND: C15.2, C16.2, C17.2, C18.2, C19.2, C20.2, C21.2, C22.2, C23.2, C24.2, C25.2, C26.2, C27.2, C28.2, D5.1 (K), D6.1 (K), D7.1 (K), D8.1 (K), R16.2, SW1.2, U1.12 (VSSA), U1.18 (VSS), U1.31 (VSS), U1.47 (VSS), U1.63 (VSS), Y1.2 (G), Y1.4 (G); also elsewhere on the board
GNSS_RX_PC11: U1.52 (PC11); also elsewhere on the board
GNSS_TX_PC10: U1.51 (PC10); also elsewhere on the board
HSE_IN: C25.1, U1.5 (PH0), Y1.1
HSE_OUT: C26.1, U1.6 (PH1), Y1.3
I2C1_SCL: U1.58 (PB6); also elsewhere on the board
I2C1_SDA: U1.59 (PB7); also elsewhere on the board
IMU_INT: U1.57 (PB5); also elsewhere on the board
ISENSE: U1.20 (PA4); also elsewhere on the board
LED_FAULT: R35.1, U1.11 (PC3)
LED_FAULT_A: D8.2 (A), R35.2
LED_FIX: R34.1, U1.10 (PC2)
LED_FIX_A: D7.2 (A), R34.2
LED_LINK: R30.1, U1.9 (PC1)
LED_LINK_A: D6.2 (A), R30.2
LED_PWR: D5.2 (A), R29.2
LORA_NRST_PA3: U1.17 (PA3); also elsewhere on the board
LORA_RX_PA1: U1.15 (PA1); also elsewhere on the board
LORA_TX_PA0: U1.14 (PA0); also elsewhere on the board
LSE_IN: C27.1, U1.3 (PC14), Y2.1
LSE_OUT: C28.1, U1.4 (PC15), Y2.2
NRST: C24.1, SW1.1, U1.7 (NRST); also elsewhere on the board
PPS_PB0: U1.26 (PB0); also elsewhere on the board
PWM_ESC_PC6: U1.37 (PC6); also elsewhere on the board
PWM_SERVO_PA8: U1.41 (PA8); also elsewhere on the board
SWCLK: U1.49 (PA14); also elsewhere on the board
SWDIO: U1.46 (PA13); also elsewhere on the board
SWO: U1.55 (PB3); also elsewhere on the board
USB_DM: U1.44 (PA11); also elsewhere on the board
USB_DP: U1.45 (PA12); also elsewhere on the board
VBAT_SENSE: U1.16 (PA2); also elsewhere on the board
VBUS_SENSE: U1.42 (PA9); also elsewhere on the board
VCAP1: C20.1, U1.30 (VCAP_1)
VDDA: C21.1, C22.1, FB1.2, U1.13 (VDDA)

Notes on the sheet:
V2 / MCU
Functional groups / electrical pin numbers / named-net connections
01 MCU and assigned interfaces
3.3 V logic. Labels define the current board wiring; fleet/ground-vehicle and handheld behavior still requires firmware and interface qualification.
02 Digital and core supply
Place each 100 nF capacitor near its VDD pin. C20 is the 4.7 uF VCAP_1-to-GND capacitor. VBAT is tied to VDD.
03 Analog supply and reset defaults
VDDA filter is fed from +3V3. BOOT0 pull-down selects flash boot; NRST is available at the debug header.
04 Clock sources
HSE: 8 MHz / CL 10 pF. LSE: 32.768 kHz / CL 7 pF. Check actual stray capacitance and startup; LSE is a population option.
05 Status indicators
Power, link, fix and fault labels describe intended application states. Firmware must define and verify the indications.
Read named nets within each group; matching labels are electrically connected. Cross-sheet signals use hierarchical ports.
V1 preserves original defects. V2 is a review draft. Bench values and firmware behavior require validation.

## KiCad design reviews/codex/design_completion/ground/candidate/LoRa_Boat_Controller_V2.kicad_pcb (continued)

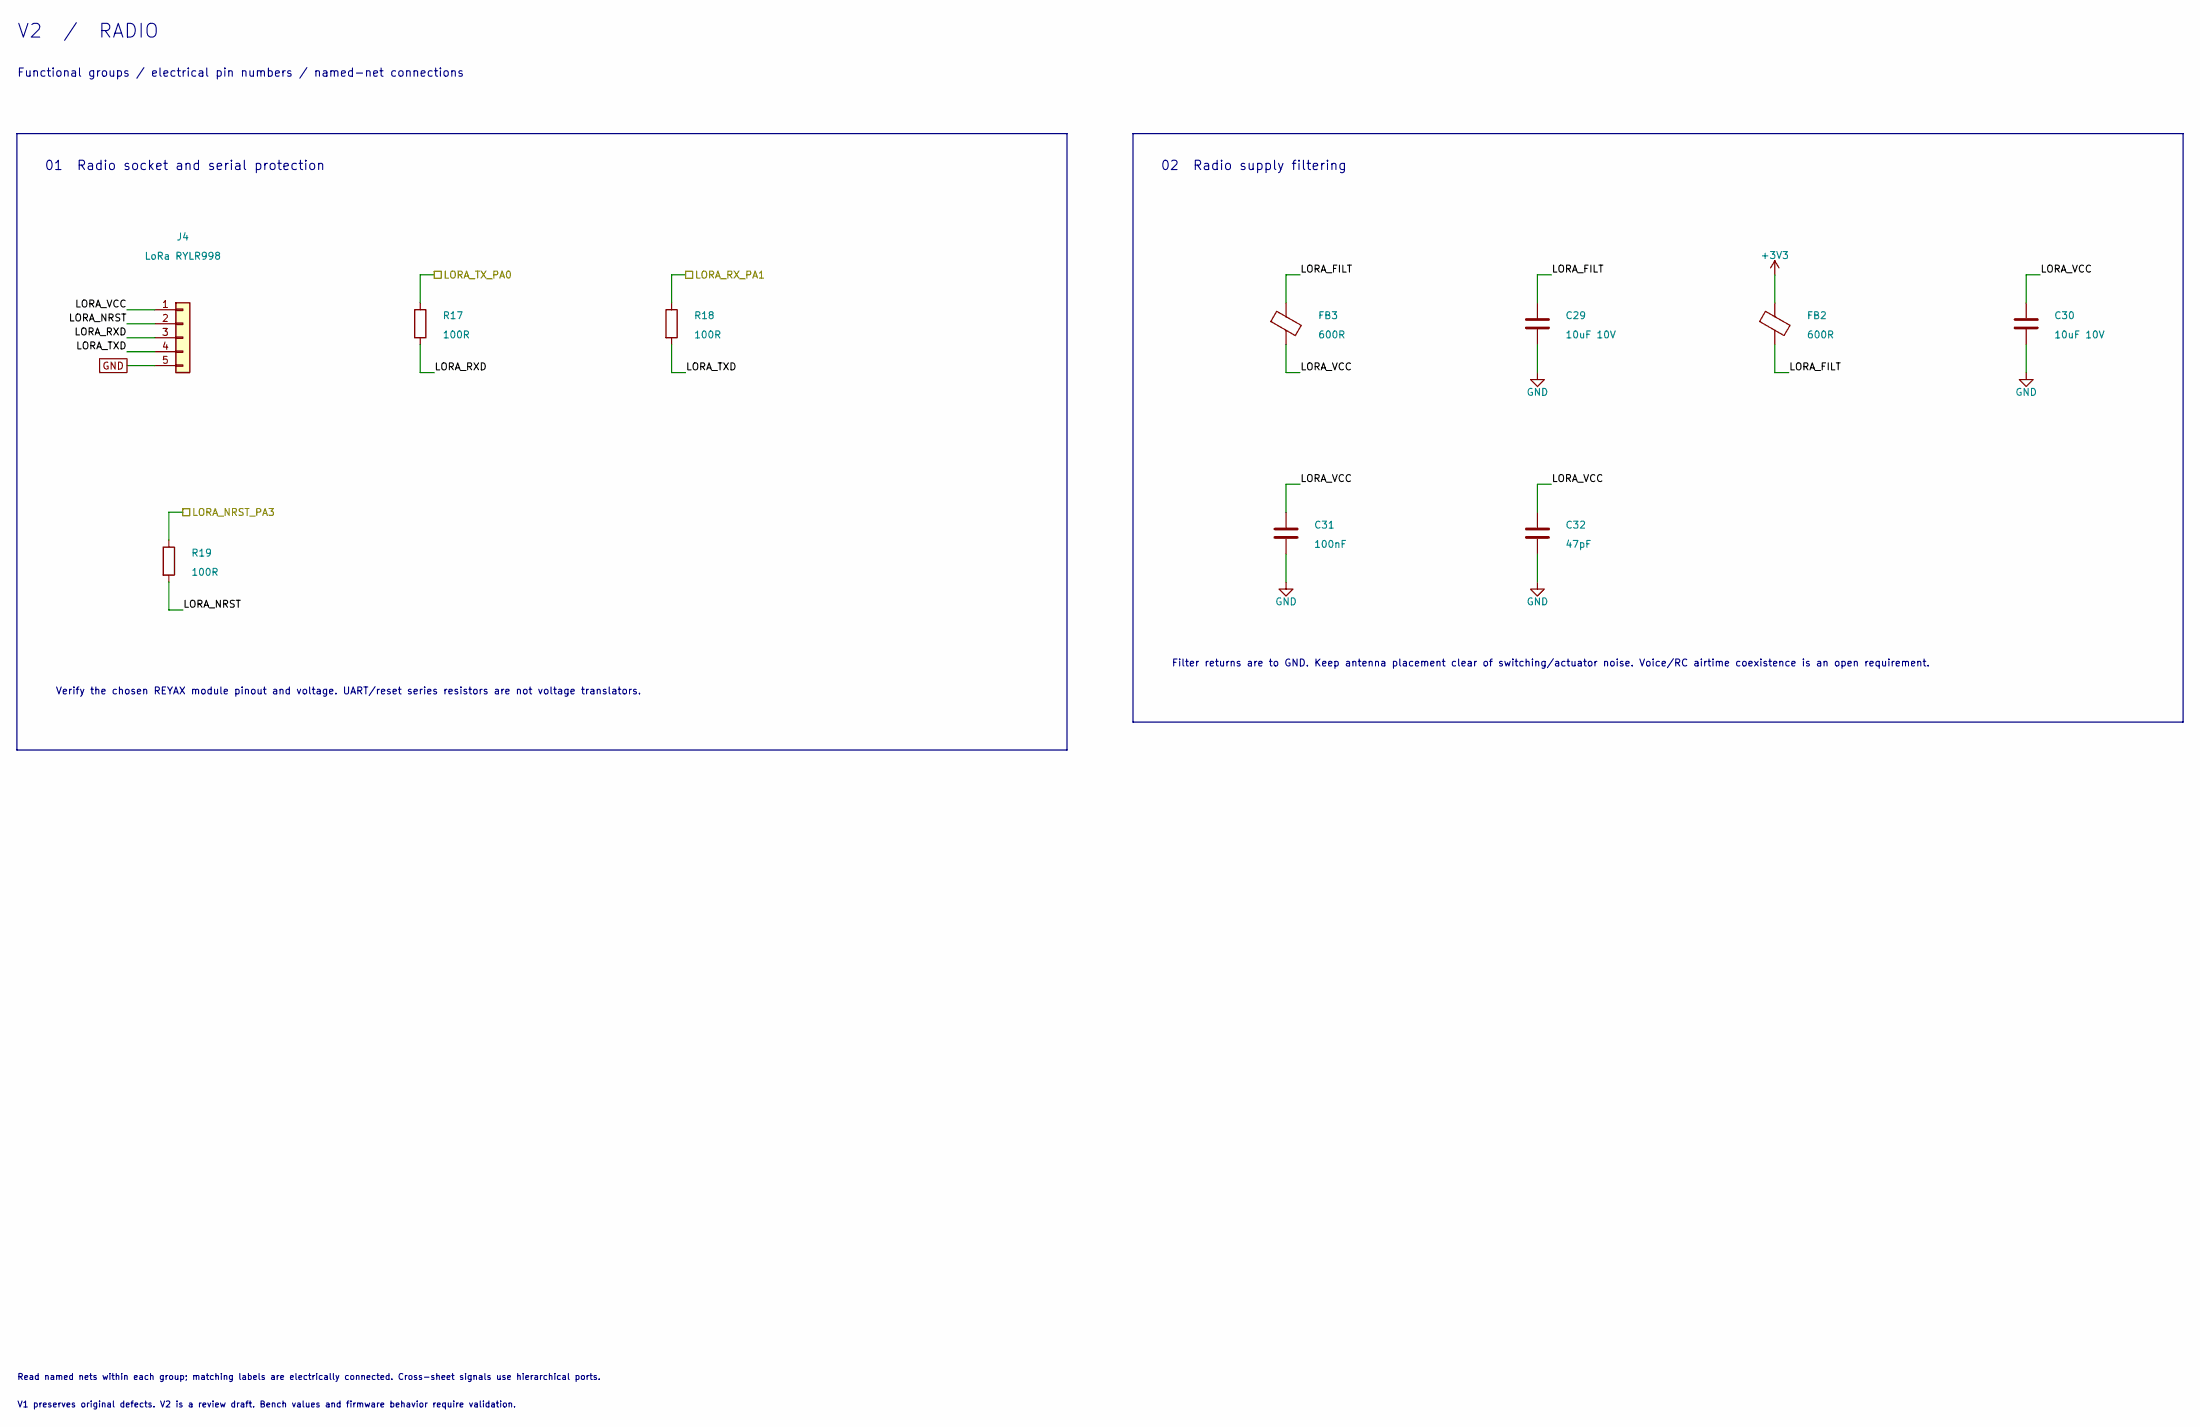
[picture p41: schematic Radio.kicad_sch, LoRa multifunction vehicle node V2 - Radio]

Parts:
C29, C30: 10uF 10V; C_0805_2012Metric; MPN GRM21BR61A106KE19L
C31: 100nF; C_0603_1608Metric; MPN KGM15ACG1H104KT
C32: 47pF; C_0402_1005Metric; MPN GJM1555C1H470JB01D
FB2, FB3: 600R; L_0402_1005Metric; MPN BLM15AG601SN1D
J4: LoRa RYLR998; CONN5_1LFBN-RC_SUL; MPN PPTC051LFBN-RC
R17, R18, R19: 100R; R_0603_1608Metric; MPN RC0603FR-07100RL

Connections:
+3V3: FB2.1; also elsewhere on the board
GND: C29.2, C30.2, C31.2, C32.2, J4.5; also elsewhere on the board
LORA_FILT: C29.1, FB2.2, FB3.1
LORA_NRST: J4.2, R19.2
LORA_NRST_PA3: R19.1; also elsewhere on the board
LORA_RXD: J4.3, R17.2
LORA_RX_PA1: R18.1; also elsewhere on the board
LORA_TXD: J4.4, R18.2
LORA_TX_PA0: R17.1; also elsewhere on the board
LORA_VCC: C30.1, C31.1, C32.1, FB3.2, J4.1

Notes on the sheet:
V2 / RADIO
Functional groups / electrical pin numbers / named-net connections
01 Radio socket and serial protection
Verify the chosen REYAX module pinout and voltage. UART/reset series resistors are not voltage translators.
02 Radio supply filtering
Filter returns are to GND. Keep antenna placement clear of switching/actuator noise. Voice/RC airtime coexistence is an open requirement.
Read named nets within each group; matching labels are electrically connected. Cross-sheet signals use hierarchical ports.
V1 preserves original defects. V2 is a review draft. Bench values and firmware behavior require validation.

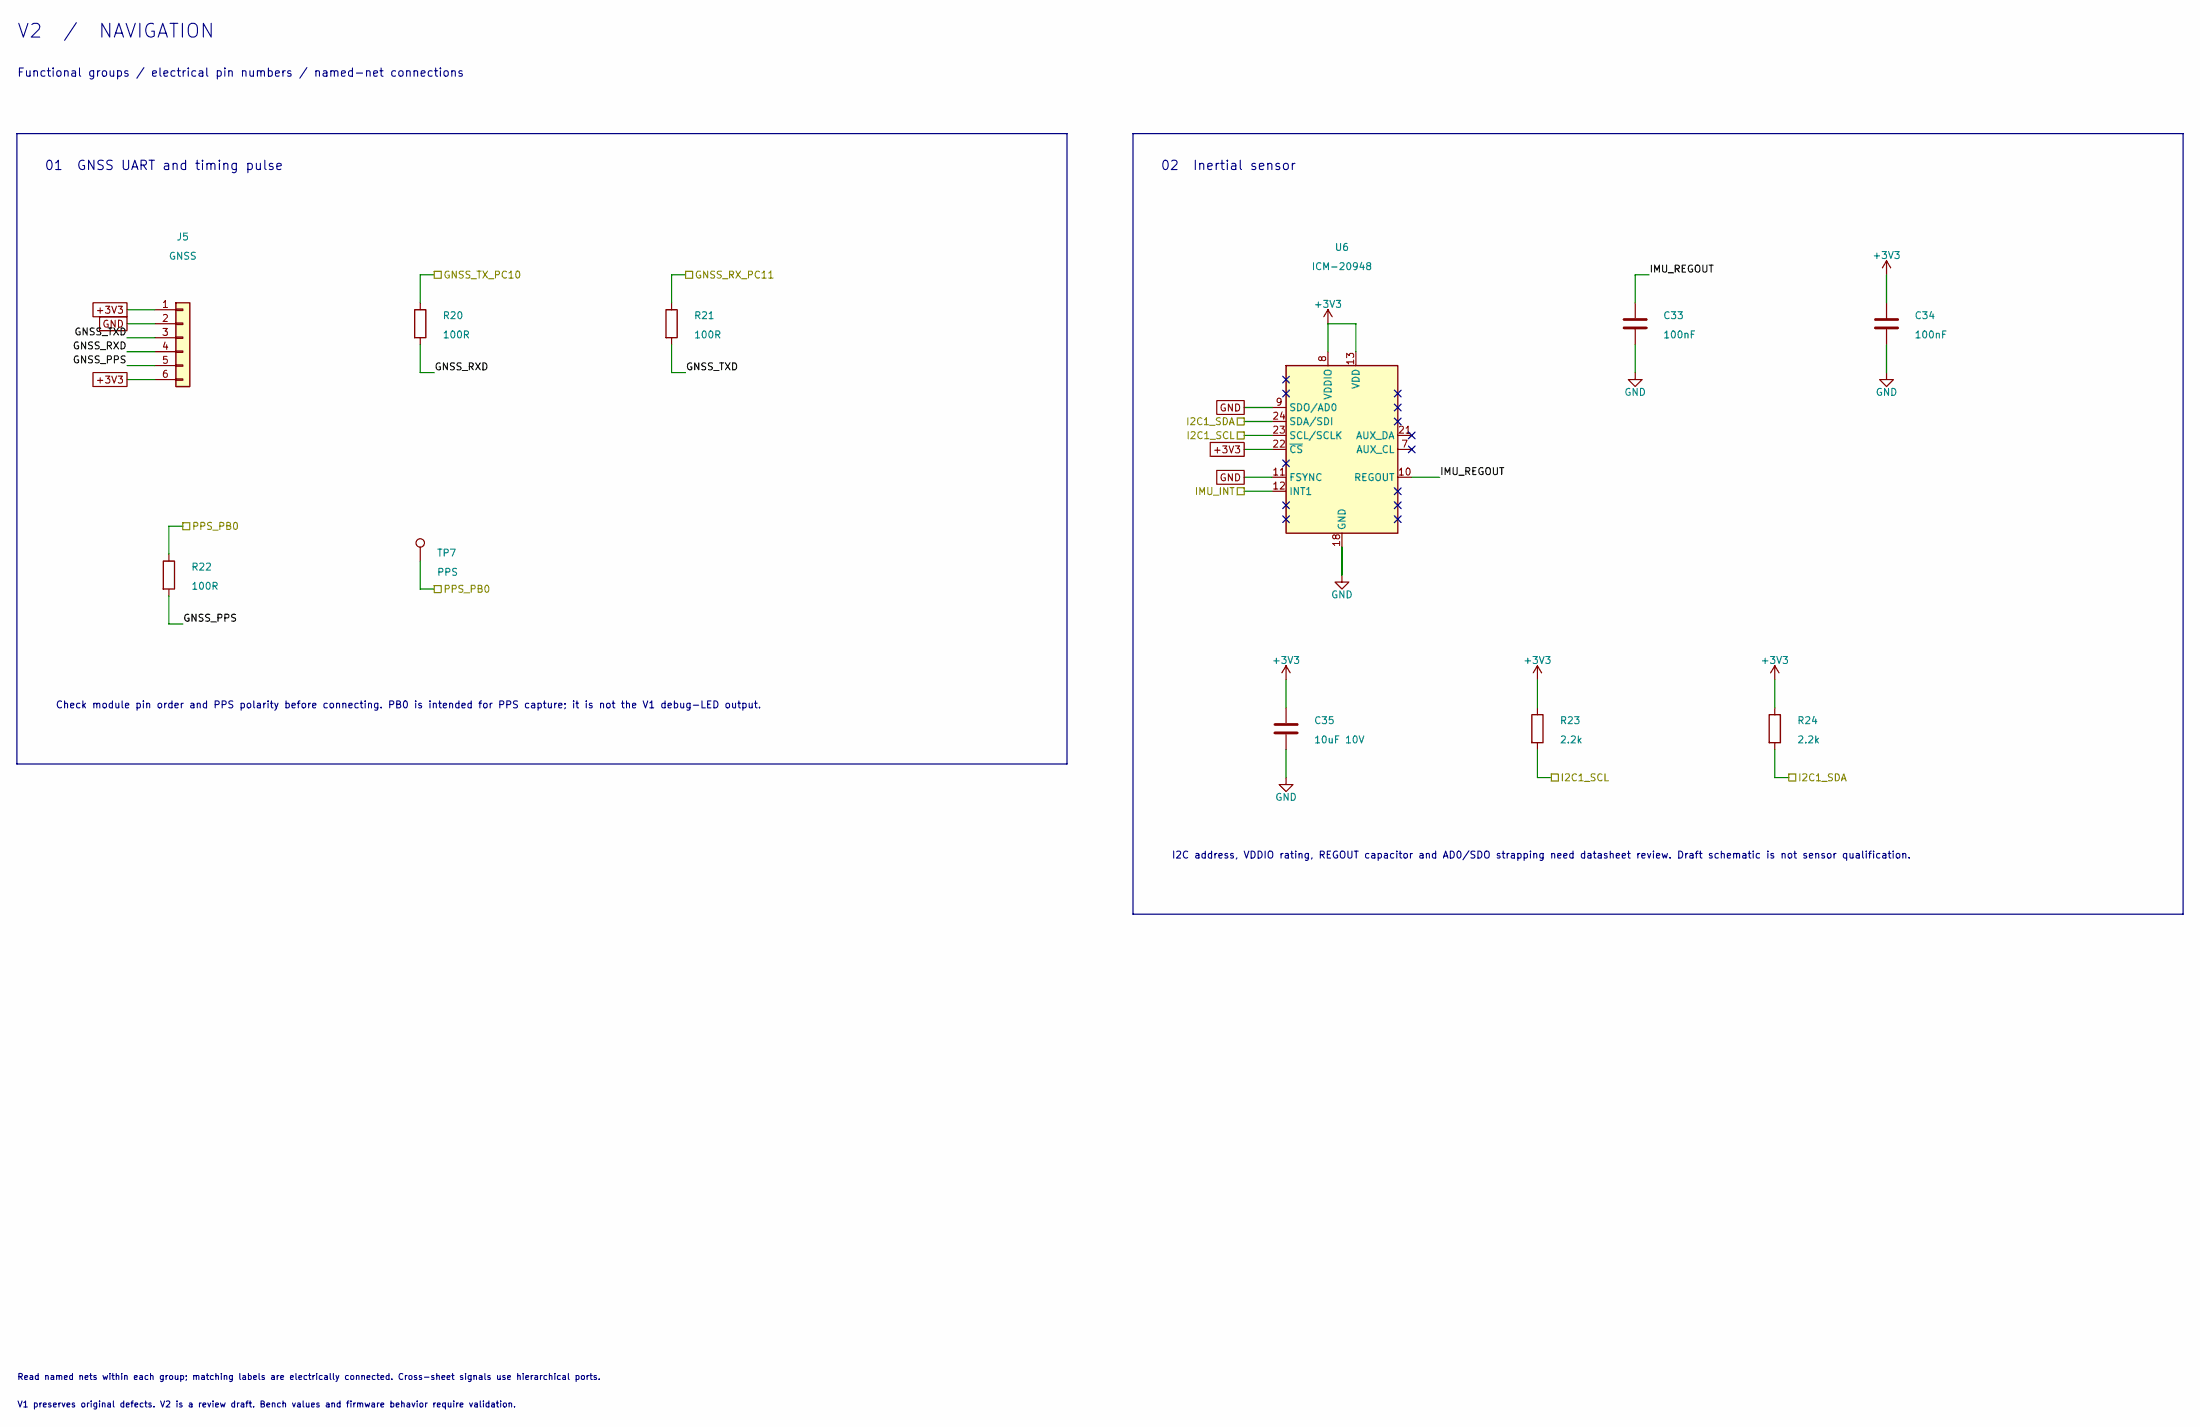
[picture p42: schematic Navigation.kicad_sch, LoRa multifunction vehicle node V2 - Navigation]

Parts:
C33, C34: 100nF; C_0603_1608Metric; MPN KGM15ACG1H104KT
C35: 10uF 10V; C_0805_2012Metric; MPN GRM21BR61A106KE19L
J5: GNSS; PinHeader_1x06_P2.54mm_Vertical; MPN PPTC061LFBN-RC
R20, R21, R22: 100R; R_0603_1608Metric; MPN RC0603FR-07100RL
R23, R24: 2.2k; R_0603_1608Metric; MPN RC0603FR-072K2L
TP7: PPS; TestPoint_Pad_D1.5mm
U6: ICM-20948; QFN-24_3x3mm_P0.4mm_NoEP; MPN ICM-20948

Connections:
+3V3: C34.1, C35.1, J5.1, J5.6, R23.1, R24.1, U6.8 (VDDIO), U6.13 (VDD), U6.22 (~CS); also elsewhere on the board
GND: C33.2, C34.2, C35.2, J5.2, U6.9 (SDO/AD0), U6.11 (FSYNC), U6.18 (GND), U6.20 (GND); also elsewhere on the board
GNSS_PPS: J5.5, R22.2
GNSS_RXD: J5.4, R20.2
GNSS_RX_PC11: R21.1; also elsewhere on the board
GNSS_TXD: J5.3, R21.2
GNSS_TX_PC10: R20.1; also elsewhere on the board
I2C1_SCL: R23.2, U6.23 (SCL/SCLK); also elsewhere on the board
I2C1_SDA: R24.2, U6.24 (SDA/SDI); also elsewhere on the board
IMU_INT: U6.12 (INT1); also elsewhere on the board
IMU_REGOUT: C33.1, U6.10 (REGOUT)
PPS_PB0: R22.1, TP7.1; also elsewhere on the board

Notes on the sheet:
V2 / NAVIGATION
Functional groups / electrical pin numbers / named-net connections
01 GNSS UART and timing pulse
Check module pin order and PPS polarity before connecting. PB0 is intended for PPS capture; it is not the V1 debug-LED output.
02 Inertial sensor
I2C address, VDDIO rating, REGOUT capacitor and AD0/SDO strapping need datasheet review. Draft schematic is not sensor qualification.
Read named nets within each group; matching labels are electrically connected. Cross-sheet signals use hierarchical ports.
V1 preserves original defects. V2 is a review draft. Bench values and firmware behavior require validation.

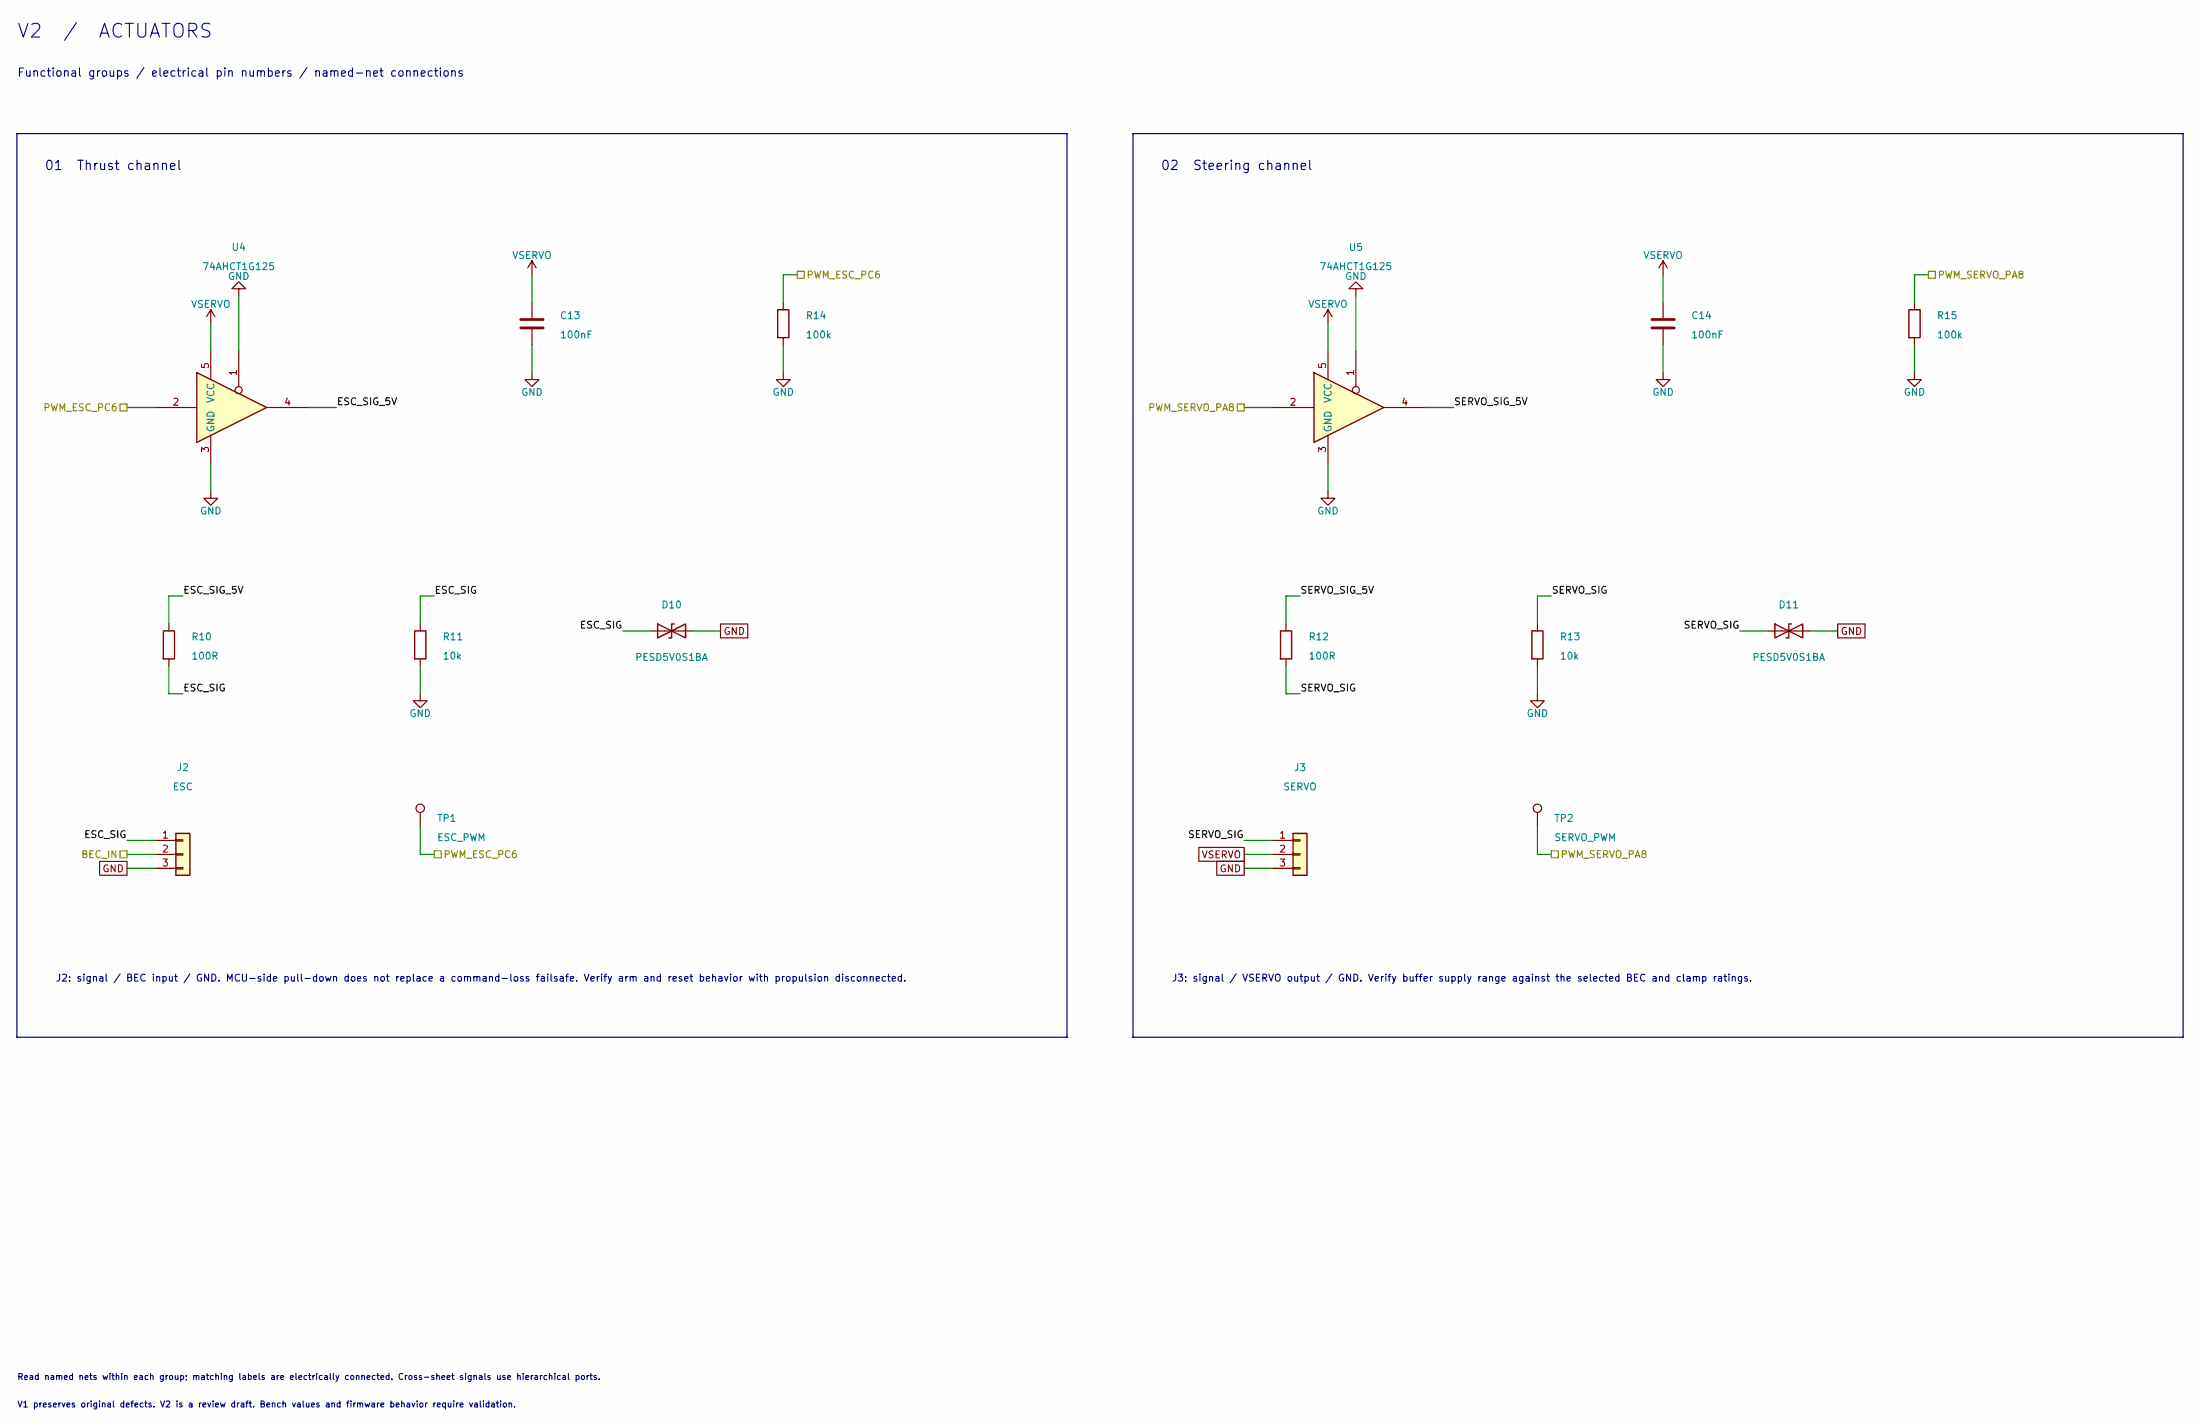
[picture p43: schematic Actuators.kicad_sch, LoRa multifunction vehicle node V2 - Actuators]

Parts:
C13, C14: 100nF; C_0603_1608Metric; MPN KGM15ACG1H104KT
D10, D11: PESD5V0S1BA; D_SOD-323; MPN PESD5V0S1BA,115
J2: ESC; JST_XH_B3B-XH-A_1x03_P2.50mm_Vertical; MPN B3B-XH-A(LF)(SN)
J3: SERVO; JST_XH_B3B-XH-A_1x03_P2.50mm_Vertical; MPN B3B-XH-A(LF)(SN)
R10, R12: 100R; R_0603_1608Metric; MPN RC0603FR-07100RL
R11, R13: 10k; R_0603_1608Metric; MPN RC0603FR-0710KL
R14, R15: 100k; R_0603_1608Metric; MPN RC0603FR-07100KL
TP1: ESC_PWM; TestPoint_Pad_D1.5mm
TP2: SERVO_PWM; TestPoint_Pad_D1.5mm
U4, U5: 74AHCT1G125; SOT-23-5; MPN SN74AHCT1G125DBVR

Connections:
BEC_IN: J2.2; also elsewhere on the board
ESC_SIG: D10.1 (A1), J2.1, R10.2, R11.1
ESC_SIG_5V: R10.1, U4.4
GND: C13.2, C14.2, D10.2 (A2), D11.2 (A2), J2.3, J3.3, R11.2, R13.2, R14.2, R15.2, U4.1, U4.3 (GND), U5.1, U5.3 (GND); also elsewhere on the board
PWM_ESC_PC6: R14.1, TP1.1, U4.2; also elsewhere on the board
PWM_SERVO_PA8: R15.1, TP2.1, U5.2; also elsewhere on the board
SERVO_SIG: D11.1 (A1), J3.1, R12.2, R13.1
SERVO_SIG_5V: R12.1, U5.4
VSERVO: C13.1, C14.1, J3.2, U4.5 (VCC), U5.5 (VCC); also elsewhere on the board

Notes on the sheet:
V2 / ACTUATORS
Functional groups / electrical pin numbers / named-net connections
01 Thrust channel
J2: signal / BEC input / GND. MCU-side pull-down does not replace a command-loss failsafe. Verify arm and reset behavior with propulsion disconnected.
02 Steering channel
J3: signal / VSERVO output / GND. Verify buffer supply range against the selected BEC and clamp ratings.
Read named nets within each group; matching labels are electrically connected. Cross-sheet signals use hierarchical ports.
V1 preserves original defects. V2 is a review draft. Bench values and firmware behavior require validation.

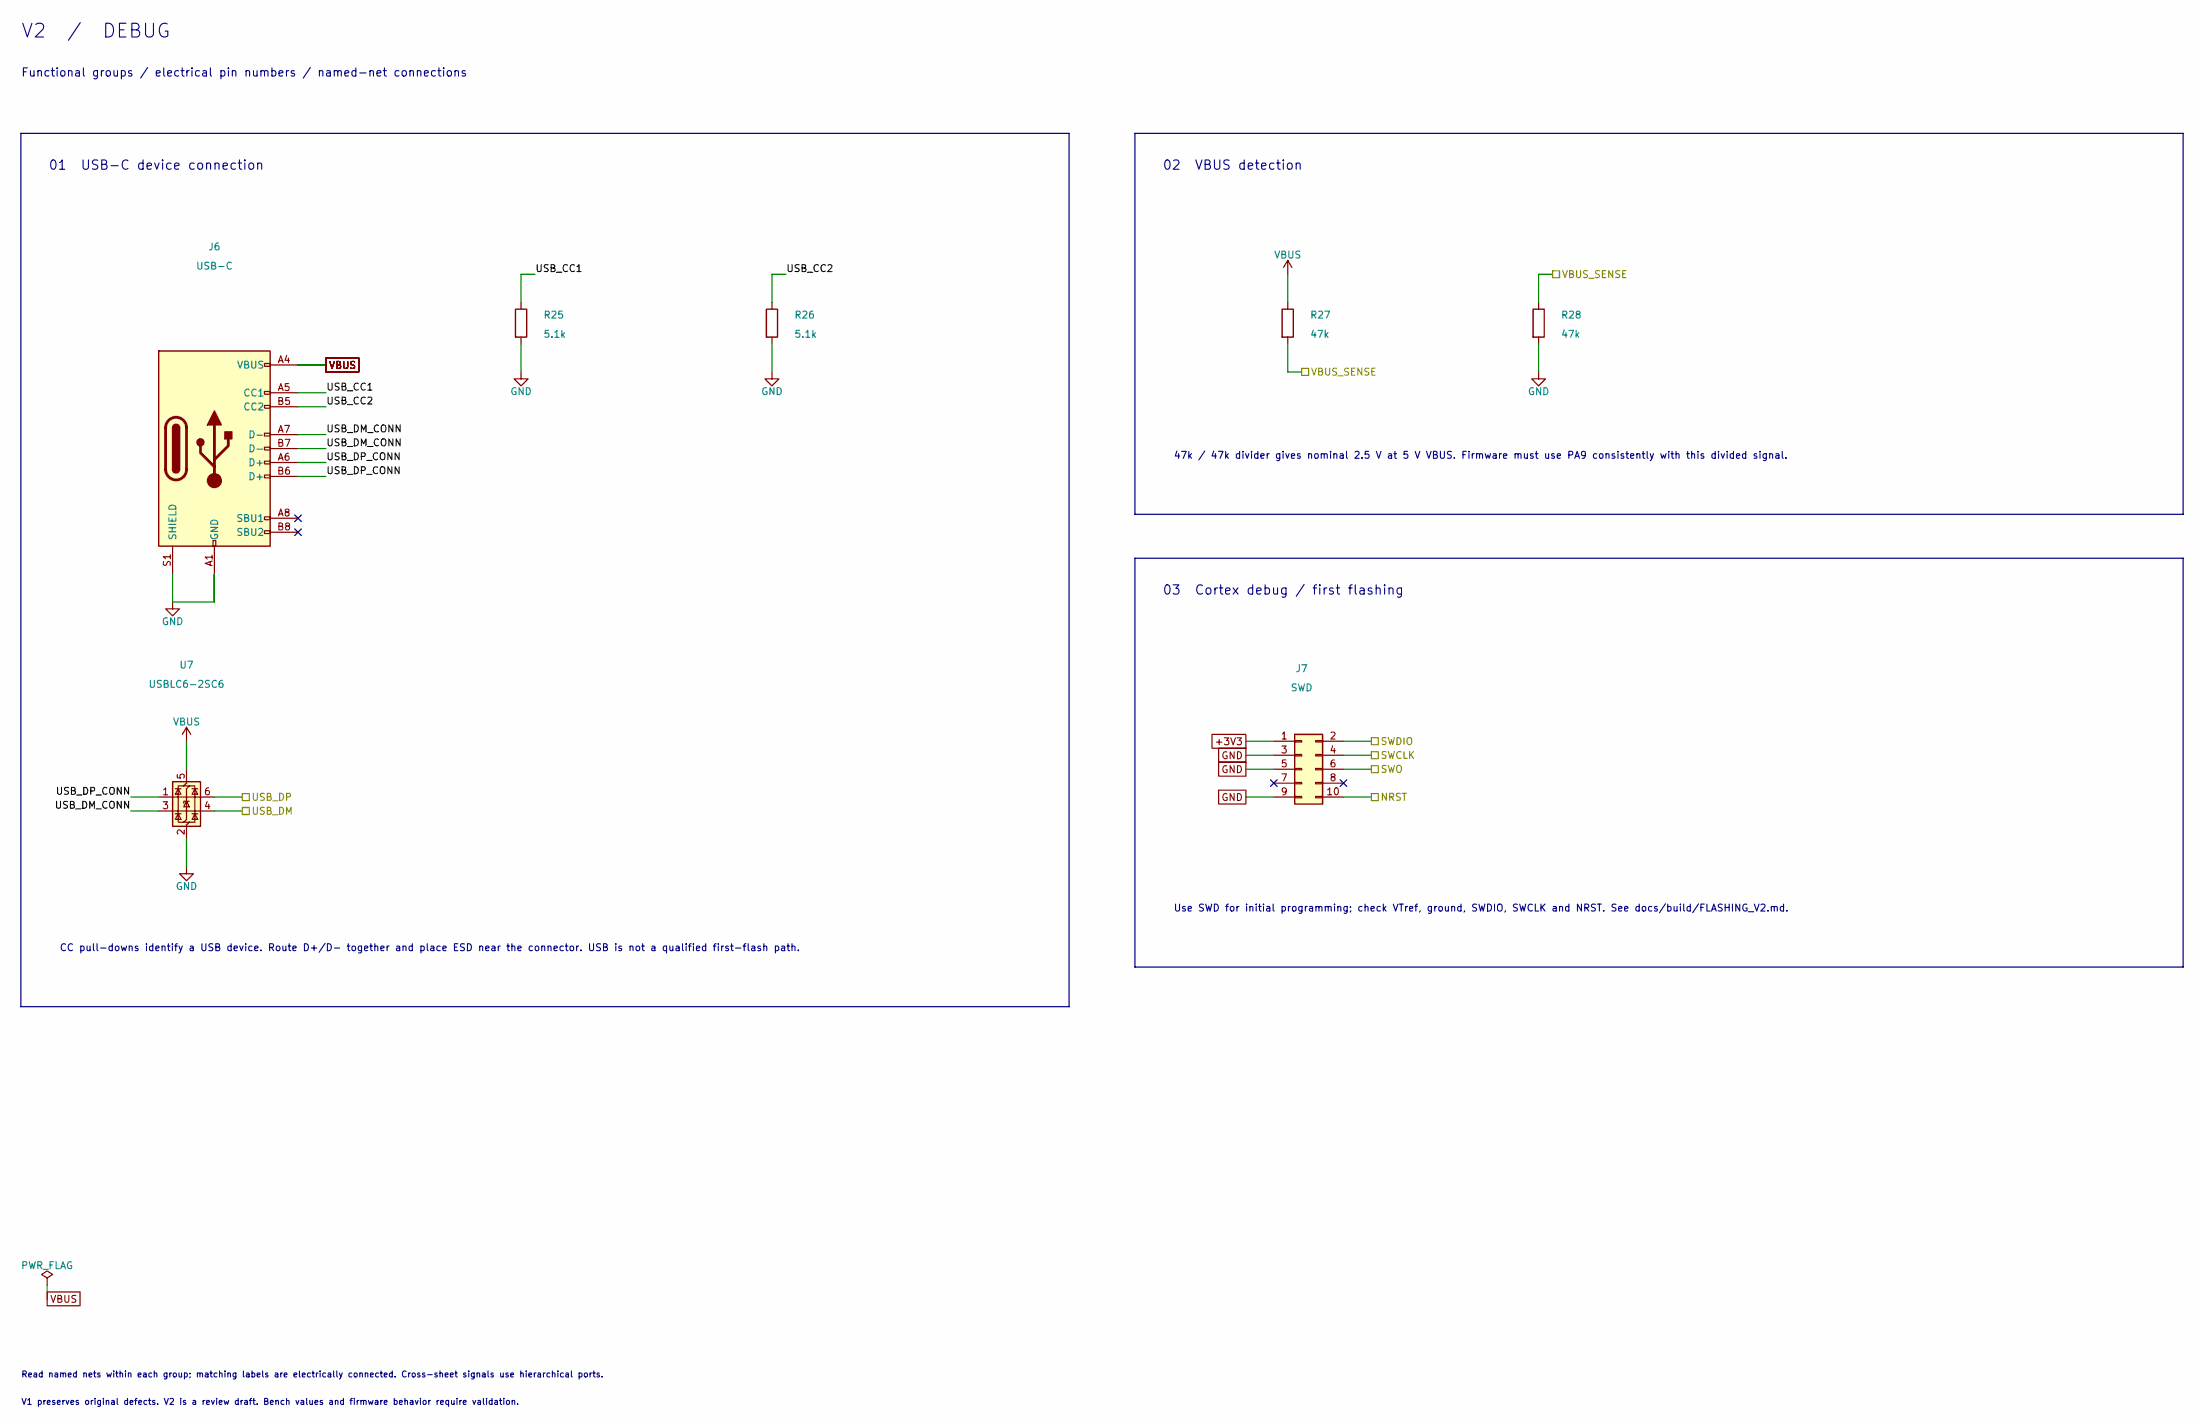
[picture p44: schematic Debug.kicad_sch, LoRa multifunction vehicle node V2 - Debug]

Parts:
J6: USB-C; USB_C_Receptacle_GCT_USB4105-xx-A_16P_TopMnt_Horizontal; MPN USB4105-GF-A
J7: SWD; PinHeader_2x05_P1.27mm_Vertical_SMD; MPN FTSH-105-01-L-DV-K
R25, R26: 5.1k; R_0603_1608Metric; MPN RC0603FR-075K1L
R27, R28: 47k; R_0603_1608Metric; MPN RC0603FR-0747KL
U7: USBLC6-2SC6; SOT-23-6; MPN USBLC6-2SC6

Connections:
+3V3: J7.1; also elsewhere on the board
GND: J6.A1 (GND), J6.A12 (GND), J6.B1 (GND), J6.B12 (GND), J6.S1 (SHIELD), J7.3, J7.5, J7.9, R25.2, R26.2, R28.2, U7.2 (GND); also elsewhere on the board
NRST: J7.10; also elsewhere on the board
SWCLK: J7.4; also elsewhere on the board
SWDIO: J7.2; also elsewhere on the board
SWO: J7.6; also elsewhere on the board
USB_CC1: J6.A5 (CC1), R25.1
USB_CC2: J6.B5 (CC2), R26.1
USB_DM: U7.4 (I/O2); also elsewhere on the board
USB_DM_CONN: J6.A7 (D-), J6.B7 (D-), U7.3 (I/O2)
USB_DP: U7.6 (I/O1); also elsewhere on the board
USB_DP_CONN: J6.A6 (D+), J6.B6 (D+), U7.1 (I/O1)
VBUS: J6.A4 (VBUS), J6.A9 (VBUS), J6.B4 (VBUS), J6.B9 (VBUS), R27.1, U7.5 (VBUS)
VBUS_SENSE: R27.2, R28.1; also elsewhere on the board

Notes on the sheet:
V2 / DEBUG
Functional groups / electrical pin numbers / named-net connections
01 USB-C device connection
CC pull-downs identify a USB device. Route D+/D- together and place ESD near the connector. USB is not a qualified first-flash path.
02 VBUS detection
47k / 47k divider gives nominal 2.5 V at 5 V VBUS. Firmware must use PA9 consistently with this divided signal.
03 Cortex debug / first flashing
Use SWD for initial programming; check VTref, ground, SWDIO, SWCLK and NRST. See docs/build/FLASHING_V2.md.
Read named nets within each group; matching labels are electrically connected. Cross-sheet signals use hierarchical ports.
V1 preserves original defects. V2 is a review draft. Bench values and firmware behavior require validation.

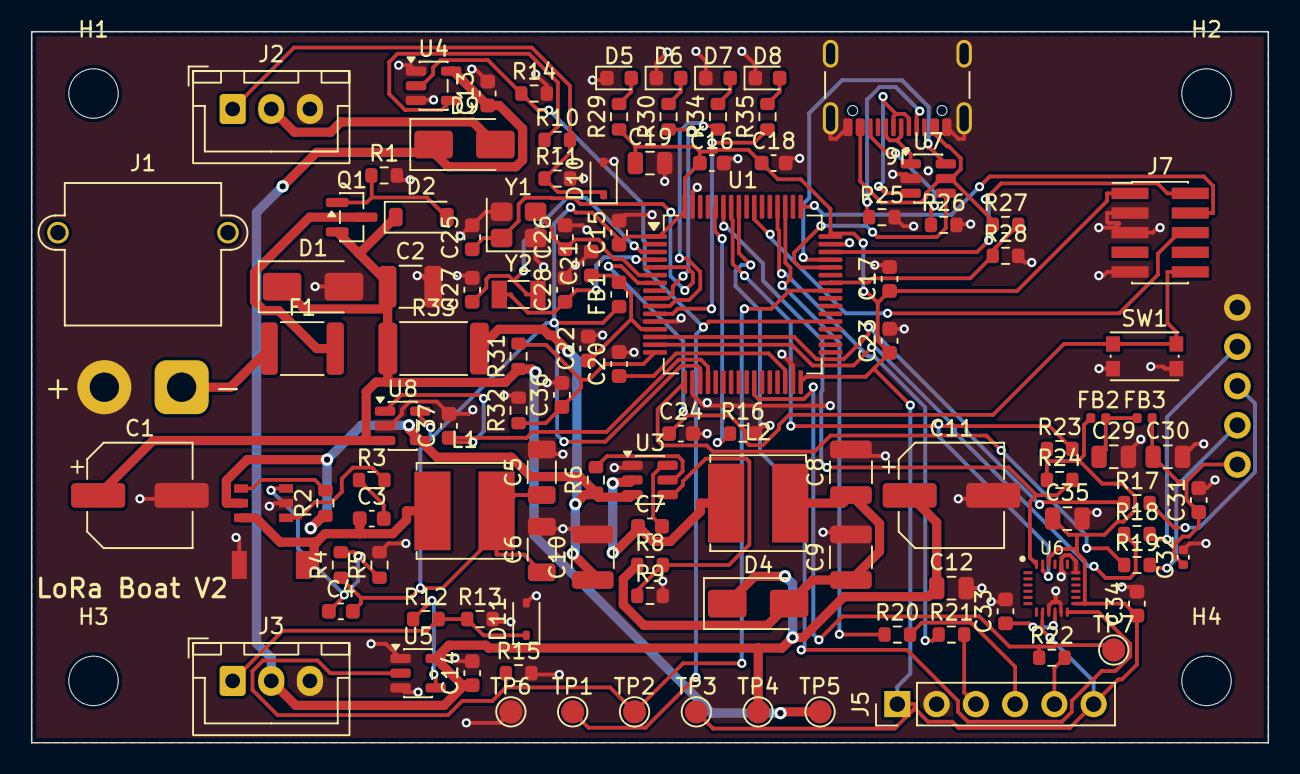
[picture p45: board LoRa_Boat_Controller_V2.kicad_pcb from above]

Board: 2 copper layers, 80.0 x 46.0 mm, 118 parts (0 on the bottom side), 71 nets.

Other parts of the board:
H1, H2, H3, H4: M3; MountingHole_3.2mm_M3

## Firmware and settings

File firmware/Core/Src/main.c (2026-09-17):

/* USER CODE BEGIN Header */
/**
  ******************************************************************************
  * @file           : main.c
  * @brief          : Main program body (Boat board – STM32F446RET: LoRa + GPS)
  ******************************************************************************
  * Peripherals (actual, based on testing):
  *   TIM1_CH1 (PA8)      -> Rudder servo PWM
  *   TIM3_CH1 (PC6)      -> Motor / Fans PWM
  *   PB0                 -> Debug LED / probe
  *
  *   UART4  (PA0 TX,  PA1 RX)   -> LoRa  @115200 (RYLR module)
  *   USART3(PC10 TX, PC11 RX)   -> GPS / DEBUG @9600
  *
  * BOARD WIRING NOTE (V1 as fabricated, verified from the v5 fab Gerbers +
  * pstxnet.dat, 2026-09-16 - see docs/V1_DESIGN_REVIEW.md, docs/img/v1_evidence_pwm.png):
  *   PA8 / TIM1_CH1 is routed to header refdes SPEEDCONTROLLER pin 2
  *   PC6 / TIM3_CH1 is routed to header refdes STEERINGSERVO  pin 2
  *   i.e. the copper is the mirror of the names used in this file: with this
  *   firmware the ESC must be plugged into the header STEERINGSERVO and the
  *   rudder servo into the header SPEEDCONTROLLER.  Do not "fix" the
  *   firmware without also re-labelling the harness; V2 renames the nets by MCU
  *   pin (PWM_PA8_ESCHDR / PWM_PC6_SERVOHDR).
  *   PB0 is wired to GPSMODULE pin 3 and is held LOW by this firmware.
  *   Other board facts that matter here: no HSE/LSE crystal (HSI only), VBAT and
  *   BOOT0 pins are unconnected, CAN transceiver RXD is on PA10 (no CAN AF).
  *
  * Behavior:
  *   - PWM:
  *       Motor:  TIM3_CH1 / PC6, 50 Hz, 1000–2000 µs
  *       Rudder: TIM1_CH1 / PA8, 50 Hz, 1100–1900 µs (center ~1500)
  *
  *   - LoRa:
  *       AT startup:
  *         ATE0
  *         AT+ADDRESS=1        (BOAT)
  *         AT+NETWORKID=18
  *         AT+BAND=915000000
  *         AT+PARAMETER=12,7,1,4
  *
  *       Incoming lines (from +RCV=...):
  *         THRUST,<0–100>
  *         RUDDER,<0–100>   (0=left, 50=center, 100=right)
  *         GPS,<lat>,<lon>  (from other node, just printed)
  *
  *   - GPS:
  *       Parse $GPRMC / $GNRMC to gps_lat/gps_lon/gps_valid.
  *       Every 5s (if valid): send "GPS,<lat>,<lon>" via LoRa AT+SEND
  *       to RC node address 2.
  ******************************************************************************
  */
/* USER CODE END Header */

/* Includes ------------------------------------------------------------------*/
#include "main.h"

/* USER CODE BEGIN Includes */
#include <string.h>
#include <stdio.h>
#include <stdlib.h>
/* USER CODE END Includes */

/* USER CODE BEGIN PD */

/* GPS / LoRa line buffers */
#define GPS_BUF_LEN    128
#define LORA_BUF_LEN   128

/* LoRa addressing – must match RC firmware */
#define LORA_ADDR_RC    2   /* Remote: RC handset (L072) */
#define LORA_ADDR_BOAT  1   /* This boat node (F446) */
#define LORA_NET_ID    18
#define LORA_FREQ      915000000UL
#define LORA_PARAM_STR "12,7,1,4"

/* Motor PWM (PC6 – TIM3_CH1) */
#define PWM_MOTOR_MIN_US     1000U   /* ESC min / idle */
#define PWM_MOTOR_MAX_US     2000U
#define PWM_MOTOR_IDLE_US    PWM_MOTOR_MIN_US

/* Rudder PWM (PA8 – TIM1_CH1) */
#define PWM_RUDDER_CENTER_US 1500U
#define PWM_RUDDER_LEFT_US   1100U   /* tune if needed */
#define PWM_RUDDER_RIGHT_US  1900U

/* USER CODE END PD */

TIM_HandleTypeDef htim1;
TIM_HandleTypeDef htim3;

UART_HandleTypeDef huart4;   // LoRa
UART_HandleTypeDef huart3;   // GPS / debug

/* USER CODE BEGIN PV */

/* GPS RX state */
static uint8_t gps_rx_byte;
static char    gps_buf[GPS_BUF_LEN];
static volatile size_t gps_len   = 0;
static volatile uint8_t gps_ready = 0;

/* LoRa RX state */
static uint8_t lora_rx_byte;
static char    lora_buf[LORA_BUF_LEN];
static volatile size_t lora_len   = 0;
static volatile uint8_t lora_ready = 0;

/* Parsed GPS data */
float   gps_lat   = 0.0f;
float   gps_lon   = 0.0f;
uint8_t gps_valid = 0;

/* Last time we sent GPS over LoRa */
uint32_t last_lora_tx = 0;

/* Motor / rudder logical values */
uint8_t thrust_value = 0;   // 0..100 (0 = stop, 100 = full)
uint8_t rudder_value = 50;  // 0..100 (0=left, 50=center, 100=right)

/* USER CODE END PV */

void SystemClock_Config(void);
static void MX_GPIO_Init(void);
static void MX_UART4_Init(void);
static void MX_USART3_UART_Init(void);
static void MX_TIM1_Init(void);
static void MX_TIM3_Init(void);
/* USER CODE BEGIN PFP */
/* Debug helper */
static void dbg(const char *s);

/* High-level helpers */
static void set_thrust(uint8_t value);
static void set_rudder(uint8_t value);

/* UART IT helpers */
static void StartGPSRxIT(void);
static void StartLoRaRxIT(void);

/* LoRa helpers */
static void lora_send_line(const char* s);
static void lora_send_payload(const char* payload);
static void parse_lora_line(char* s);

/* GPS helpers */
static int  gps_ddmm_to_deg(const char* val, const char* hemi, float* out);
static int  gps_validate_checksum(const char* s);
static void gps_parse_rmc(char* line);
static void gps_task(void);
/* USER CODE END PFP */

/* USER CODE BEGIN 0 */

static void dbg(const char *s)
{
  if (!s) return;
  /* Use finite timeout so a broken UART doesn't hard-lock */
  HAL_UART_Transmit(&huart3, (uint8_t*)s, strlen(s), 100);
}

/* Start interrupt receive for both UARTs */
static void StartGPSRxIT(void)
{
  HAL_UART_Receive_IT(&huart3, &gps_rx_byte, 1);
}

static void StartLoRaRxIT(void)
{
  HAL_UART_Receive_IT(&huart4, &lora_rx_byte, 1);
}

/* Simple AT line sender (adds \r\n) */
static void lora_send_line(const char* s)
{
  if (!s) return;

  /* Finite timeouts here too */
  HAL_UART_Transmit(&huart4, (uint8_t*)s, strlen(s), 100);
  uint8_t crlf[2] = { '\r', '\n' };
  HAL_UART_Transmit(&huart4, crlf, 2, 100);
}

/* AT+SEND payload helper:
 *  - Boat node address  = LORA_ADDR_BOAT (1)
 *  - RC handset address = LORA_ADDR_RC   (2)
 *  We send GPS/etc *to the RC*, so destination = LORA_ADDR_RC.
 */
static void lora_send_payload(const char* payload)
{
  if (!payload) return;
  char cmd[128];
  snprintf(cmd, sizeof(cmd),
           "AT+SEND=%d,%u,%s",
           LORA_ADDR_RC,           /* send TO RC (2) */
           (unsigned)strlen(payload),
           payload);
  lora_send_line(cmd);
}

/* Convert ddmm.mmmm -> decimal degrees */
static int gps_ddmm_to_deg(const char* val, const char* hemi, float* out)
{
  if (!val || !*val || !out) return 0;
  double v       = atof(val);
  int    deg     = (int)(v / 100);
  double minutes = v - (deg * 100.0);
  double result  = deg + minutes / 60.0;
  if (hemi && (*hemi == 'S' || *hemi == 'W')) result = -result;
  *out = (float)result;
  return 1;
}

/* Validate NMEA checksum */
static int gps_validate_checksum(const char* s)
{
  if (!s || s[0] != '$') return 0;
  const char* star = strrchr(s, '*');
  if (!star) return 0;

  uint8_t chk = 0;
  for (const char* p = s + 1; p < star; p++)
  {
    chk ^= (uint8_t)(*p);
  }
  uint8_t given = (uint8_t)strtol(star + 1, NULL, 16);
  return (chk == given);
}

/* Parse an RMC line (in-place strtok) */
static void gps_parse_rmc(char* line)
{
  if (!gps_validate_checksum(line)) return;

  char* toks[16];
  int   n = 0;

  for (char* tok = strtok(line, ","); tok && n < 16; tok = strtok(NULL, ","))
  {
    toks[n++] = tok;
  }
  if (n < 7) return;

  if (strncmp(toks[0], "$GPRMC", 6) != 0 &&
      strncmp(toks[0], "$GNRMC", 6) != 0)
  {
    return;
  }

  /* Status: A = active, V = void */
  if (toks[2][0] != 'A')
  {
    gps_valid = 0;
    return;
  }

  float lat, lon;
  if (!gps_ddmm_to_deg(toks[3], toks[4], &lat)) return;
  if (!gps_ddmm_to_deg(toks[5], toks[6], &lon)) return;

  gps_lat   = lat;
  gps_lon   = lon;
  gps_valid = 1;
}

/* GPS processing task (call from main loop) */
static void gps_task(void)
{
  if (!gps_ready) return;
  gps_ready = 0;

  char buf[GPS_BUF_LEN];
  strncpy(buf, gps_buf, sizeof(buf));
  buf[GPS_BUF_LEN - 1] = '\0';

  if (strncmp(buf, "$GPRMC", 6) == 0 || strncmp(buf, "$GNRMC", 6) == 0)
  {
    gps_parse_rmc(buf);
  }
}

/* Parse one LoRa line from RYLR ("+RCV=...") */
static void parse_lora_line(char* s)
{
  if (!s) return;

  /* Skip leading CR/LF/spaces so "\r+RCV=..." still matches */
  while (*s == '\r' || *s == '\n' || *s == ' ' || *s == '\t')
  {
    s++;
  }

  if (*s == '\0') return;

  /* Expect lines like:
   *   +RCV=1,10,THRUST,50,-50,12
   *   +RCV=1,10,RUDDER,30,-70,11
   */
  if (strncmp(s, "+RCV=", 5) != 0 && strncmp(s, "RCV=", 4) != 0)
  {
    return;
  }

  /* Skip header up to second comma, then data starts */
  char* p = s;
  int   comma_count = 0;
  while (*p && comma_count < 2)
  {
    if (*p == ',') comma_count++;
    p++;
  }
  if (comma_count < 2) return;  // malformed
  char* data = p;               // points at payload: "THRUST,50,..."

  /* Normalize: strip trailing \r or \n */
  char* end = data + strlen(data);
  while (end > data && (end[-1] == '\r' || end[-1] == '\n'))
  {
    *--end = '\0';
  }

  /* Commands:
   *  THRUST,<0-100>
   *  RUDDER,<0-100>
   *  GPS,<lat>,<lon>
   */

  if (strncmp(data, "THRUST,", 7) == 0)
  {
    int value;
    if (sscanf(data, "THRUST,%d", &value) == 1)
    {
      if (value < 0)   value = 0;
      if (value > 100) value = 100;
      thrust_value = (uint8_t)value;
      set_thrust(thrust_value);

      char dbg_buf[64];
      snprintf(dbg_buf, sizeof(dbg_buf), "LoRa: THRUST=%d\r\n", value);
      dbg(dbg_buf);
    }
  }
  else if (strncmp(data, "RUDDER,", 7) == 0)
  {
    int value;
    if (sscanf(data, "RUDDER,%d", &value) == 1)
    {
      if (value < 0)   value = 0;
      if (value > 100) value = 100;
      rudder_value = (uint8_t)value;
      set_rudder(rudder_value);

      char dbg_buf[64];
      snprintf(dbg_buf, sizeof(dbg_buf), "LoRa: RUDDER=%d\r\n", value);
      dbg(dbg_buf);
    }
  }
  else if (strncmp(data, "GPS,", 4) == 0)
  {
    float lat, lon;
    if (sscanf(data, "GPS,%f,%f", &lat, &lon) == 2)
    {
      char dbg_buf[80];
      snprintf(dbg_buf, sizeof(dbg_buf),
               "LoRa: GPS from RC: %.6f, %.6f\r\n", lat, lon);
      dbg(dbg_buf);
    }
  }
}

/* Set motor thrust (0..100) → TIM3_CH1 / PC6 */
static void set_thrust(uint8_t value)
{
  if (value > 100) value = 100;

  uint32_t range = (PWM_MOTOR_MAX_US - PWM_MOTOR_MIN_US); // 1000
  uint32_t pulse = PWM_MOTOR_MIN_US + (range * value) / 100U;

  __HAL_TIM_SET_COMPARE(&htim3, TIM_CHANNEL_1, pulse);
  thrust_value = value;
}

/* Set rudder (0..100) → TIM1_CH1 / PA8
 * 0   = fully left  (PWM_RUDDER_LEFT_US)
 * 50  = center      (PWM_RUDDER_CENTER_US)
 * 100 = fully right (PWM_RUDDER_RIGHT_US)
 */
static void set_rudder(uint8_t value)
{
  if (value > 100) value = 100;

  uint32_t range = (PWM_RUDDER_RIGHT_US - PWM_RUDDER_LEFT_US);
  uint32_t pulse = PWM_RUDDER_LEFT_US + (range * value) / 100U;

  __HAL_TIM_SET_COMPARE(&htim1, TIM_CHANNEL_1, pulse);
  rudder_value = value;
}

/* USER CODE END 0 */

/**
  * @brief  The application entry point.
  * @retval int
  */

int main(void)
{
  /* MCU Configuration--------------------------------------------------------*/

  /* Reset of all peripherals, Initializes the Flash interface and the Systick. */
  HAL_Init();   // sets up uwTick, SysTick, HAL_Delay, etc.

  /* Configure the system clock */
  SystemClock_Config();

  /* Initialize all configured peripherals */
  MX_GPIO_Init();
  MX_UART4_Init();
  MX_USART3_UART_Init();
  MX_TIM1_Init();
  MX_TIM3_Init();

  /* NVIC setup for UART interrupts (must match stm32f4xx_it.c IRQHandlers) */
  HAL_NVIC_SetPriority(UART4_IRQn, 5, 0);
  HAL_NVIC_EnableIRQ(UART4_IRQn);

  HAL_NVIC_SetPriority(USART3_IRQn, 5, 0);
  HAL_NVIC_EnableIRQ(USART3_IRQn);

  /* Start PWM on both channels */
  if (HAL_TIM_PWM_Start(&htim1, TIM_CHANNEL_1) != HAL_OK) { Error_Handler(); }
  if (HAL_TIM_PWM_Start(&htim3, TIM_CHANNEL_1) != HAL_OK) { Error_Handler(); }

  /* Safe startup: motor idle, rudder centered */
  set_thrust(0);
  set_rudder(50);

  /* Let ESC/servo/LoRa/GPS power up */
  HAL_Delay(1500);

  /* Start UART reception in interrupt mode */
  StartGPSRxIT();
  StartLoRaRxIT();

  /* Configure LoRa module via AT commands */
  lora_send_line("ATE0");                        // Echo off
  lora_send_line("AT+ADDRESS=1");                // This node address (boat)
  lora_send_line("AT+NETWORKID=18");             // Network ID
  lora_send_line("AT+BAND=915000000");           // 915 MHz
  lora_send_line("AT+PARAMETER=" LORA_PARAM_STR);// SF12, BW index 7 = 125 kHz (not 7.8 kHz), CR4/5, preamble 4. NOTE: an RYLR998 rejects SF12 (SF5-11 only) and keeps its stored settings; only the RYLR896 accepts SF12.

  dbg("Boat: LoRa init done\r\n");

  /* Infinite loop */
  while (1)
  {
    /* Handle GPS parsing */
    gps_task();

    /* Process any complete LoRa line */
    if (lora_ready)
    {
      lora_ready = 0;
      char buf_local[LORA_BUF_LEN];
      strncpy(buf_local, lora_buf, sizeof(buf_local));
      buf_local[LORA_BUF_LEN - 1] = '\0';

      dbg("LORA RX: ");
      dbg(buf_local);
      dbg("\r\n");

      parse_lora_line(buf_local);
    }

    uint32_t now = HAL_GetTick();

    /* Send *our* GPS over LoRa every 5 seconds if valid */
    if (gps_valid && (now - last_lora_tx >= 5000U))
    {
      char payload[64];
      snprintf(payload, sizeof(payload), "GPS,%.6f,%.6f", gps_lat, gps_lon);
      lora_send_payload(payload);
      last_lora_tx = now;
    }

    HAL_Delay(10);
  }
}

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
/* USER CODE BEGIN 4 */

/* UART receive complete callback (called from IRQs via HAL_UART_IRQHandler) */
void HAL_UART_RxCpltCallback(UART_HandleTypeDef *huart)
{
  if (huart->Instance == USART3)  /* GPS */
  {
    char c = (char)gps_rx_byte;

    if (c == '\n')
    {
      gps_buf[gps_len] = '\0';
      gps_ready = 1;
      gps_len = 0;
    }
    else
    {
      if (gps_len < (GPS_BUF_LEN - 1))
      {
        gps_buf[gps_len++] = c;
      }
    }
    StartGPSRxIT();
  }
  else if (huart->Instance == UART4)  /* LoRa */
  {
    char c = (char)lora_rx_byte;

    if (c == '\n')
    {
      lora_buf[lora_len] = '\0';
      lora_ready = 1;
      lora_len = 0;
    }
    else
    {
      if (lora_len < (LORA_BUF_LEN - 1))
      {
        lora_buf[lora_len++] = c;
      }
    }
    StartLoRaRxIT();
  }
}

/* USER CODE END 4 */
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


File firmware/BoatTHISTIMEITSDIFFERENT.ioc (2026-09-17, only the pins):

Mcu.UserName=STM32F446RETx
PA0-WKUP.Signal=UART4_TX
PA1.Signal=UART4_RX
PA13.Signal=SYS_JTMS-SWDIO
PA14.Signal=SYS_JTCK-SWCLK
PA15.Signal=SYS_JTDI
PA8.Signal=S_TIM1_CH1
PB0.Signal=GPIO_Output
PB3.Signal=SYS_JTDO-SWO
PC10.Signal=USART3_TX
PC11.Signal=USART3_RX
PC6.Signal=S_TIM3_CH1

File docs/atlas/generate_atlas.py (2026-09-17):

"""Generate the V1 connector atlas from source snapshots (standard library only).

Run from any directory with Python 3.10+: python docs/atlas/generate_atlas.py
Use --check to verify committed/generated outputs against the current sources.
Writes only docs/atlas/*.md and pm/data/connectors.json. Never imports CAD tools.
"""
import argparse
import csv
import datetime as dt
import hashlib
import io
import json
from pathlib import Path
import re
import xml.etree.ElementTree as ET

ROOT = Path(__file__).resolve().parents[2]
PST = "Allegro/hardware/allegro-original/Allegro v5/Allegro/pstxnet.dat"
MAP = "docs/atlas/evidence/v1-netmap.json"
BOM = "docs/BOM.csv"
XML = "docs/atlas/evidence/v1-netlist.xml"
PROVENANCE = "docs/atlas/evidence/provenance.json"
MAIN = "firmware/Core/Src/main.c"
MSP = "firmware/Core/Src/stm32f4xx_hal_msp.c"
IOC = "firmware/BoatTHISTIMEITSDIFFERENT.ioc"
DS = "docs/research/DATASHEET_NOTES.md"
SELF = "docs/atlas/generate_atlas.py"
INPUTS = (PST, MAP, BOM, XML, MAIN, MSP, IOC, DS, PROVENANCE, SELF)
RAW = {p: (ROOT / p).read_bytes() for p in INPUTS}
TEXT = {p: raw.decode("utf-8-sig").replace("\r\n", "\n") for p, raw in RAW.items()}
MANIFEST = [{"path": p, "sha256": hashlib.sha256(RAW[p]).hexdigest(), "bytes": len(RAW[p])} for p in INPUTS]
for artifact in json.loads(TEXT[PROVENANCE])["artifacts"]:
    raw = RAW[artifact["path"]]
    if len(raw) != artifact["bytes"] or hashlib.sha256(raw).hexdigest() != artifact["sha256"]:
        raise ValueError("Preserved V1 evidence differs from its provenance: " + artifact["path"])


def evidence(path, needle):
    index = TEXT[path].find(needle)
    if index < 0:
        raise ValueError(f"Reviewed evidence no longer matches {path}: {needle!r}; review before regenerating")
    return {"path": path, "line": TEXT[path].count("\n", 0, index) + 1}


def cite(item):
    return f"[{item['path']}:{item['line']}](../../{item['path'].replace(' ', '%20')}#L{item['line']})"


def ev(path, needle):
    return cite(evidence(path, needle))


def parse_pst():
    nets = {}
    for match in re.finditer(r"(?m)^NET_NAME\s*\n'([^\n]+)'\s*\n([\s\S]*?)(?=^NET_NAME|^END\.|\Z)", TEXT[PST]):
        name, body = match.groups()
        nodes = []
        for node in re.finditer(r"(?m)^NODE_NAME\s+(\S+)\s+(\d+)\s*\n[^\n]*\n\s*'([^']*)'", body):
            ref, raw_pin, label = node.groups()
            nodes.append({"ref": ref, "pin": str(int(raw_pin)), "allegro_pin": raw_pin, "label": label,
                          "line": TEXT[PST].count("\n", 0, match.start(2) + node.start()) + 1})
        assert nodes, f"Unparsed net {name}"
        nets[name] = nodes
    assert len(nets) == len(re.findall(r"(?m)^NET_NAME\s*$", TEXT[PST]))
    assert sum(map(len, nets.values())) == len(re.findall(r"(?m)^NODE_NAME\s", TEXT[PST]))
    return nets


NETS = parse_pst()
NETMAP = json.loads(TEXT[MAP])
BOMS = {r["Allegro_RefDes"]: r for r in csv.DictReader(io.StringIO(TEXT[BOM]))}
KREF = {r["Ref"]: a for a, r in BOMS.items()}
XML_NETS = {}
for net in ET.fromstring(TEXT[XML]).find("nets"):
    members = frozenset((KREF[n.get("ref")], str(int(n.get("pin")))) for n in net.findall("node"))
    XML_NETS[members] = net.get("name")

# Guard reviewed behavioral claims: changed firmware needs renewed human/agent review.
for token in ["__HAL_TIM_SET_COMPARE(&htim3, TIM_CHANNEL_1, pulse)",
              "__HAL_TIM_SET_COMPARE(&htim1, TIM_CHANNEL_1, pulse)",
              "HAL_GPIO_WritePin(GPIOB, GPIO_PIN_0, GPIO_PIN_RESET)",
              "huart4.Init.BaudRate   = 115200", "huart3.Init.BaudRate   = 9600",
              "#define PWM_MOTOR_MIN_US     1000U", "#define PWM_MOTOR_MAX_US     2000U",
              "#define PWM_RUDDER_CENTER_US 1500U", "#define PWM_RUDDER_LEFT_US   1100U",
              "#define PWM_RUDDER_RIGHT_US  1900U", "sConfigOC.Pulse      = PWM_MOTOR_IDLE_US",
              "if (gps_valid && (now - last_lora_tx >= 5000U))"]:
    evidence(MAIN, token)
assert len(re.findall(r"\bHAL_GetTick\s*\(", TEXT[MAIN])) == 1, "Re-review link-loss behavior before regeneration"
assert "MX_CAN" not in TEXT[MAIN], "Re-review CAN implementation"
assert "GPIO_PIN_3" not in TEXT[MAIN], "Re-review LoRa reset configuration"
evidence(IOC, "TIM3.Pulse-PWM\\ Generation1\\ CH1=1500")

COMMON = "Electrical pin numbers below come from v5 pstxnet.dat, not a physical left-to-right view. Board side, connector key, cable view, and pin-1 marking require physical verification. All voltages and waveforms are design/code expectations, not bench measurements."
ACTUATOR = "V1 connector names conflict with firmware roles: SPEEDCONTROLLER pin 2 carries the firmware rudder waveform; STEERINGSERVO pin 2 carries the firmware thrust waveform. Treat both as electrical identities until harness labels and physical continuity are verified."
POWER = "Pin 1 is on the board +3V3 rail. ESC/BEC/servo external power compatibility and current budget are unverified; this is not a certified actuator power port."
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

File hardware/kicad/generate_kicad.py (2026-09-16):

#!/usr/bin/env python3
"""
Generate KiCad 9 project files from extracted Allegro DSN design data.
LoRa Autonomous Boat Controller - Cadence Allegro to KiCad conversion.

Source: senior design v2.dsn (Specctra DSN export from Allegro PCB Editor 22.1)
Target: STM32F446RET6 + TCAN1042H + R1240N + LoRa/GPS modules
"""

import json, uuid, os, time

# Load extracted design data
with open('design_data.json', 'r') as f:
    data = json.load(f)

placements = data['placements']
nets = data['nets']

# ============================================================
# FOOTPRINT MAPPING: Allegro -> KiCad standard library
# ============================================================
FOOTPRINT_MAP = {
    # 0402 caps (1005 metric)
    "CAP_CL05_SAM": "Capacitor_SMD:C_0402_1005Metric",
    # 0603 caps
    "CAP_0603_CL10A_1P6XP8_SAM": "Capacitor_SMD:C_0603_1608Metric",
    "CAP_CL10_SAM": "Capacitor_SMD:C_0603_1608Metric",
    "CAP_0603G_AVX": "Capacitor_SMD:C_0603_1608Metric",
    "CAPC17595_95N_KEM": "Capacitor_SMD:C_0603_1608Metric",
    "CAP_GJM1555C1H220JB01__MUR": "Capacitor_SMD:C_0402_1005Metric",
    # Larger caps
    "G-21_MUR": "Capacitor_SMD:C_0805_2012Metric",
    "G-31_MUR": "Capacitor_SMD:C_1206_3216Metric",
    "CAP_NTS_55_2P8T_NIP": "Capacitor_SMD:C_1210_3225Metric",
    # Resistors
    "RC0402N_PAN": "Resistor_SMD:R_0402_1005Metric",
    "RC0402N_YAG": "Resistor_SMD:R_0402_1005Metric",
    "RC0603N_YAG": "Resistor_SMD:R_0603_1608Metric",
    "RES_1005_SAM": "Resistor_SMD:R_0402_1005Metric",
    "RES_R0805_ROM": "Resistor_SMD:R_0805_2012Metric",
    # Inductors
    "IND_1608_TDK": "Inductor_SMD:L_0603_1608Metric",
    "IND_BLM15_0402_MUR": "Inductor_SMD:L_0402_1005Metric",
    # ICs
    "LQFP64-10X10MM": "Package_QFP:LQFP-64_10x10mm_P0.5mm",
    "D0008A_L": "Package_SO:SOIC-8_3.9x4.9mm_P1.27mm",
    "SOT-323-3_2X1P25_ONS": "Package_TO_SOT_SMD:SOT-323_SC-70",
    "SOT-23-6W_PE-SOT23-6W-0512_NMD": "Package_TO_SOT_SMD:SOT-23-6",
    # Connectors
    "CONN_B4B-XH-A_JST": "Connector_JST:JST_XH_B4B-XH-A_1x04_P2.50mm_Vertical",
    "CONN_PPTC031_SUL": "Connector_PinHeader_2.54mm:PinHeader_1x03_P2.54mm_Vertical",
    "CONN_SBH11-PBPC-D05-ST-BK_SUL": "Connector_IDC:IDC-Header_2x05_P2.54mm_Vertical",
    "CONN5_1LFBN-RC_SUL": "Connector_PinHeader_2.54mm:PinHeader_1x05_P2.54mm_Vertical",
    # Test points & terminals
    "AMV_TEST_POINT": "TestPoint:TestPoint_Pad_D1.0mm",
    "AMV_CON1": "Connector_PinHeader_2.54mm:PinHeader_1x01_P2.54mm_Vertical",
    "AMC_TEST_POINT": "TestPoint:TestPoint_Pad_D1.0mm",
}

def get_kicad_footprint(allegro_fp):
    """Map Allegro footprint name to KiCad library footprint."""
    # Strip the per-component suffix (e.g. _C1, _U3, etc)
    base = allegro_fp.strip("'")
    # Try progressively shorter prefixes
    for key in sorted(FOOTPRINT_MAP.keys(), key=len, reverse=True):
        if base.startswith(key):
            return FOOTPRINT_MAP[key]
    return f"LoRa_Boat_Controller:{base}"  # fallback to project lib

# ============================================================
# SYMBOL MAPPING: Component values -> KiCad symbol library
# ============================================================
def get_kicad_symbol(ref, value):
    """Map component to KiCad symbol library reference."""
    if ref.startswith('C'):
        return "Device:C"
    elif ref.startswith('R'):
        return "Device:R"
    elif ref.startswith('L'):
        return "Device:L"
    elif ref == 'U3':
        return "MCU_ST:STM32F446RETx"
    elif ref == 'U5':
        return "Interface_CAN_LIN:TCAN1042"
    elif ref == 'U6':
        return "Regulator_Switching:R1240N001x"  # custom, will need lib
    elif ref == 'U1':
        return "Device:D_Schottky"  # ESD protection
    elif ref.startswith('TP'):
        return "Connector:TestPoint"
    elif ref in ('GND', 'VIN'):
        return "Connector:Conn_01x01_Pin"
    elif ref in ('CANHEADER',):
        return "Connector:Conn_01x04_Pin"
    elif ref in ('SPEEDCONTROLLER', 'STEERINGSERVO'):
        return "Connector:Conn_01x03_Pin"
    elif ref == 'JTAG':
        return "Connector:Conn_02x05_Odd_Even"
    elif ref in ('GPSMODULE', 'LORAMODULE'):
        return "Connector:Conn_01x05_Pin"
    return "Device:R"  # fallback

# ============================================================
# STM32F446RET6 PIN MAP (LQFP-64)
# ============================================================
STM32_PINS = {
    1: "VBAT", 2: "PC13", 3: "PC14", 4: "PC15", 5: "PH0", 6: "PH1",
    7: "NRST", 8: "PC0", 9: "PC1", 10: "PC2", 11: "PC3", 12: "VSSA",
    13: "VDDA", 14: "PA0", 15: "PA1", 16: "PA2", 17: "PA3", 18: "VSS",
    19: "VDD", 20: "PA4", 21: "PA5", 22: "PA6", 23: "PA7", 24: "PC4",
    25: "PC5", 26: "PB0", 27: "PB1", 28: "PB2", 29: "PB10", 30: "PB11",
    31: "VCAP_1", 32: "VDD", 33: "PB12", 34: "PB13", 35: "PB14",
    36: "PB15", 37: "PC6", 38: "PC7", 39: "PC8", 40: "PC9",
    41: "PA8", 42: "PA9", 43: "PA10", 44: "PA11", 45: "PA12",
    46: "PA13", 47: "VSS", 48: "VDD", 49: "PA14", 50: "PA15",
    51: "PC10", 52: "PC11", 53: "PC12", 54: "PD2", 55: "PB3",
    56: "PB4", 57: "PB5", 58: "PB6", 59: "PB7", 60: "BOOT0",
    61: "PB8", 62: "PB9", 63: "VSS", 64: "VDD"
}

# ============================================================
# Net name cleanup 
# ============================================================
NET_NAME_MAP = {
    "0": "GND",
    "3.3V": "+3V3",
    "N088060": "VIN_RAW",
    "N068040": "VREG_OUT",
    "N18028": "SW_NODE",
    "N17576": "FB_DIV",
    "N17942": "BST",
    "N055670": "EN",
    "N061071": "COIL_SENSE",
    "N04429": "LORA_VCC",
    "N04477": "LORA_TX",
    "N04485": "LORA_RX",
    "N24517": "LORA_RST",
    "N04277": "GPS_RX",
    "N04281": "GPS_TX_PC11",
    "N04285": "GPS_TX_PC10",
    "N04755": "CAN_TX",
    "N04759": "CAN_RX",
    "N04763": "CAN_STB",
    "N04855": "CANH",
    "N24691": "CANL",
    "N24886": "CAN_VCC",
    "N04355": "PWM_MOTOR",
    "N04395": "PWM_RUDDER",
    "N27410": "LORA_FILT",
    "N27791": "VCAP1",
    "ADC": "ADC_VBAT",
    "VBAT": "VBAT",
    "RESET": "NRST",
    "PA14TCLK": "JTAG_TCK",
    "'PA13": "SWDIO",
    "'PA14": "SWCLK",
    "'PA15": "JTDI",
    "'PB3": "JTDO_SWO",
    "GND": "GND_BAT",
}

def clean_net_name(n):
    return NET_NAME_MAP.get(n, n)
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

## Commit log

2026-04-01 Initial Upload
    [BOM.csv, CAPC17595_95N_KEM.step, CAP_0603G_AVX.step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]
2026-09-16 Snapshot pre-reconstruction state before Phase A
    Adds the untracked KiCad sub-sheets, stale pipeline docs (STATUS/SESSION_HANDOFF/DIRECTIVES),
    the agent brief (AGENT_PROMPT_V2.md), and the legacy DSN converter that were left uncommitted
    by the previous session. Nothing here is validated; it is captured so the reconstruction diff
    is reviewable. .gitignore now excludes .claude/, *.lck, _backup_*/ and KiCad autosaves.
    [CAN_Bus.kicad_sch, GPS_Module.kicad_sch, LoRa_Boat_Controller.kicad_pcb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]
2026-09-17 Phase A2: faithful V1 PCB reconstruction from v5 fab films
    Reconstruction pipeline in hardware/kicad/tools (provenance, v5_reconstruct, gen_footprints, gen_pcb,
    validate_pcb, xor_compare, build_v1). Board is rebuilt from BOATCREW*.art + pstxnet.dat, not the stale DSN v2.
    Validated: 172/172 pads at 0.000 mil, DRC 0 errors / 0 unconnected, Gerber XOR F.Cu 0.87 % B.Cu 0.23 %,
    drill 53/53. Research notes (datasheets, BOM MPNs, firmware review) added under docs/research.
    [LoRa_Boat_Controller.kicad_pcb, senior design v2.dsn]
2026-09-17 Phase A3: hierarchical V1 schematic generated from pstxnet.dat, ERC clean, netlist == pstxnet
    gen_symbols.py (R1240N001x, TCAN1042H-Q1, CMS06 diode, VIN_RAW power symbol per current datasheets),
    kicad_sym.py (flattened embedding of KiCad 9 library symbols), gen_sch.py (7 sub-sheets mirroring the OrCAD
    blocks, labels/hierarchical pins/power symbols, deterministic symbol paths shared with the PCB via v1_design.py),
    check_netlist.py (schematic and board nets == pstxnet.dat, refs and footprint paths match).
    ERC 0 violations with --severity-all. Allegro refdes without a trailing digit get a '1' suffix (KiCad annotation
    rule); original kept in the Allegro_RefDes property.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
    [CAN_Bus.kicad_sch, Debug.kicad_sch, GPS_Module.kicad_sch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]
2026-09-17 Phase A3 close: CANH/CANL net names corrected, BOM with MPNs, DSN-v2 comparison, schematic exports
    - gen_pcb.py: N04855 is CANL (U5 pin 6) and N24691 is CANH (U5 pin 7) per pstxnet.dat + TI SLLSES9D; the
    old NETLIST.md had them reversed (Codex review finding R03).
    - gen_bom.py: docs/BOM.csv regenerated from the schematic with MPN/manufacturer/description/confidence/price
    columns (research in docs/research/BOM_MPN_RESEARCH.md, prices 2026-09-16).
    - a0_xor_dsn.py: DSN v2 copper vs v5 films = 54 % / 63 % mismatch, 0 of 20 vias coincide, 0 of 45 parts unmoved;
    the DSN wiring is unusable for v5 (documented in docs/A0_PROVENANCE.md).
    - Schematic PDF and per-sheet SVG exports in docs/img.
    Gat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
    [BOM.csv, CAN_Bus.kicad_sch, Debug.kicad_sch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]
2026-09-17 A4: copper-evidence figures (PWM, VCAP, CAN) and firmware comment-only wiring notes; prompt for the Codex agent
    main.c behaviour unchanged: header now states the copper-verified mapping (PA8/TIM1 -> SPEEDCONTROLLER header,
    PC6/TIM3 -> STEERINGSERVO header, PB0 -> GPS pin 3, no crystal, VBAT/BOOT0 floating) and corrects the
    'BW7.8' comment (index 7 = 125 kHz; RYLR998 rejects SF12).
    [main.c]
2026-09-17 Phase A4 + B: README, design review, V2 requirements, firmware plan, generated NETLIST/INDEX/CONVERSION_NOTES, archived stale docs
    - docs/V1_DESIGN_REVIEW.md: 30 findings with copper/datasheet/firmware evidence, the three resolved questions,
    link budget (two-ray over water), airtime table, control-loop and power analysis.
    - docs/V2_REQUIREMENTS.md: REQ-RF/CTL/PWR/NAV/MCU/DBG/FW/MECH/CAN with verification, 10 decisions with defaults.
    - firmware/V2_FIRMWARE_PLAN.md: V2 pin map, failsafe/watchdog behaviour, protocol, drivers, link-loss test.
    - gen_docs.py regenerates NETLIST.md (32 nets, changed-in-V2 column), the footprint table and INDEX.md.
    - README.md rewritten with the corrected file map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
    [generate_atlas.py]
2026-09-17 Phase C: V2 schematic (6 sheets, ERC clean) and placed, DRC-clean unrouted PCB generated by hardware/kicad_v2/tools
    - v2_design.py: 118 parts / 71 nets, 80 x 46 mm board, 4 x M3 holes, PLACE table legalised (0 courtyard overlaps; XT30 flush at the left edge, USB-C at the top edge)
    - gen_v2.py: project library (VSERVO power symbol, QFN-24 3x3 P0.4 no-EP footprint with 0.2 x 0.6 mm pads so corner pads clear by 0.21 mm), schematic + root sheet, PCB with GND pours, .kicad_pro (Def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
    - placement_check.py (KiCad python): courtyard overlaps / off-board report -> _build/placement.json
    - route_v2.py (KiCad python): DSN export -> freerouting 2.1.0 -> SES i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
    [Actuators.kicad_sch, Debug.kicad_sch, LoRa_Boat_Controller_V2.kicad_pcb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]
2026-09-17 Codex snapshot: pm viewer scaffold, S2 independent verification packet, firmware protocol prototype, coordination appends
    Files under pm/** and reviews/codex/** are Codex-owned (FILE_OWNERSHIP.md); committed as-is by the primary agent, which owns git commits.
    [CAN_Bus.kicad_sch, Debug.kicad_sch, GPS_Module.kicad_sch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]
2026-09-17 Phase C: V2 board autorouted (freerouting 2.1.0, B.Cu GND plane), DRC 0 violations, priced BOM_V2, REPORT.md, V2 docs
    - route_v2.py: DSN export with --gnd-plane bcu (freerouting drops a via next to every top-side GND pad), SES import, pour fill,
    GND stitch pass for pads the pours cannot reach (3 remain: J3-3, J5-2, J6 S1 - see HANDOFF pause note)
    - netclasses retuned for the autorouter: Default 0.25 mm / 0.15 mm, Power 0.6 mm / 0.2 mm limited to coarse-pad nets;
    board rules 0.127 mm min; GND pours with solid pad connections (thermal 0.25/0.3 for the rest)
    - board: 1074 track segments, 164 vias, 3 unconnected GND pins, 0 DRC violations; silkscreen title moved off the LEDs
    - docs: docs/BOM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
    [BOM_V2.csv, LoRa_Boat_Controller_V2.kicad_pcb]
2026-09-17 Codex snapshot: pm viewer (V1), V1 connector atlas, S2 verification write-up and analysis JSON
    Codex-owned paths committed as-is by the primary agent (Codex ran out of usage mid-flight; see HANDOFF pause note).
2026-09-17 Phase C draft closed: GND stitch pass, review fixes (U3 no-connect, D2 10 V, VBUS divider), renders, docs index, release notes
    - route_v2.py: isolated GND clusters found by union-find over the filled pour outlines (joined through vias and THT pads),
    stitched with straight or L-shaped 0.25 mm tracks to the connected pour, accepted only when the unconnected count drops;
    1 of 3 islands stitched on this layout, 2 remain for hand-finish (documented in hardware/kicad_v2/README.md and REPORT.md)
    - gen_v2.py: V2 no longer inherits the V1 FORCE_NC (TPS54202 pin 1 had a no-connect flag in the schematic); GND pours solid-connected
    - v2_design.py: D2 BZT52C10 (10 V clamp, AO3401A Vgs max 12 V), R28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
    [BOM_V2.csv, Debug.kicad_sch, LoRa_Boat_Controller_V2.kicad_pcb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]
2026-09-17 Publish reviewed LoRa engineering workspace and portfolio handoff
    [Actuators.kicad_sch, BOM.csv, BOM_V2.csv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]
2026-09-17 Repair V2 ground connectivity and add diagnostic application guides
    [Actuators.kicad_sch, CAN_Bus.kicad_sch, Debug.kicad_sch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]
2026-09-17 Record V2 verification and refresh corrected PCB previews
2026-09-18 Add verified 1.8 V IMU interface candidate and review guide
    [Actuators.kicad_sch, Debug.kicad_sch, LoRa_Boat_Controller_V2.kicad_sch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]
2026-09-18 Document IMU placement limits and native routing obstacles
    Preserve all original PCB objects in an isolated mechanical study. Record courtyard fit, 136 native errors, affected copper, the bias-filter reserve and 6S power-envelope dependency. Add viewer access and six preservation rejection tests. Staged tree d13f6c7ac0eacb3a6c4883be864f4dbdb6eddf91 passed clean-source publication checks and viewer rebuild; desktop/phone UI and 228 local links passed. Live CAD and unrelated local tool edits remain unchanged.
    [IMU_PLACEMENT_STUDY.kicad_pcb, LoRa_Boat_Controller_V2.kicad_pcb, normalized_baseline.kicad_pcb]
2026-09-19 Add verified IMU2 translator bias filter and review guide
    Add only C43=100pF to an isolated schematic copy, preserving all 398 prior pin memberships and the original ERC finding. Preserve IMU1/placement/live CAD evidence. Seven acceptance/rejection tests, r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
2026-10-12 Document 6S power boundary and hold mismatched input parts
    Capture nine power-boundary nets and 24 reference inventories with zero electrical or copper delta. Add reviewed C1/F1 package and D2 value findings, candidate-space map, purchasing holds, viewer and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
    Validation: independent source/limit review; 52 unchanged CAD hashes; publication/ordering checks; desktop and phone viewer checks; nine staged artifact hashes. Captured KiCad library CRLF bytes pres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
2026-10-12 Add native-checked 6S input-stage schematic candidate
    Capture INPUT-A1 as an isolated wired fuse/TVS/series-diode study with held exact parts, annotated drawings, native exports and preservation manifests. Verify 344 outside-boundary memberships and fourteen rejection cases; link the candidate in the viewer and portfolio.
    Live CAD, corrected copper, purchasing and firmware remain unchanged. Discharged-output reverse leakage is the next circuit gate; no power, fabrication or hardware acceptance is claimed.
    Validated tree: 55ac53cca414bc4ba089ed91c3574f3bc1b11046. Portable publication checks, native comparison, package capture, and desktop/phone viewer checks pass. Native SVG whitespace is p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
2026-10-12 Document reverse-leakage limits and add interactive startup review
    A diode-only bleeder calculation does not protect the complete input boundary, and Panasonic prohibits reverse voltage on the selected polarized C1. Preserve INPUT-A1 while recording the capacitor constraint, total-current uncertainty, ADC startup limits and the next reservoir/buck-input selection task.
    Add a tested analytical model, native-boundary capture, desktop/phone scenario viewer, source citations, evidence hashes and portfolio/handoff links. Seven tests and ten scenarios per viewport pass. All 52 live CAD hashes and prior packets are preserved; no new native or hardware acceptance is claimed.
    Validated tree: 1a99db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
2026-10-13 Define 3.3 V observation error and fault-response allocation
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2026-11-06 Add isolated SENSE-02 filter correction and verified viewer evidence
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
